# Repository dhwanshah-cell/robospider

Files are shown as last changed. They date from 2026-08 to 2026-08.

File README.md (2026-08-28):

# RoboSpider

A 12-DOF sprawled quadruped, simulated in MuJoCo and sized against the servos
it will actually be built with.

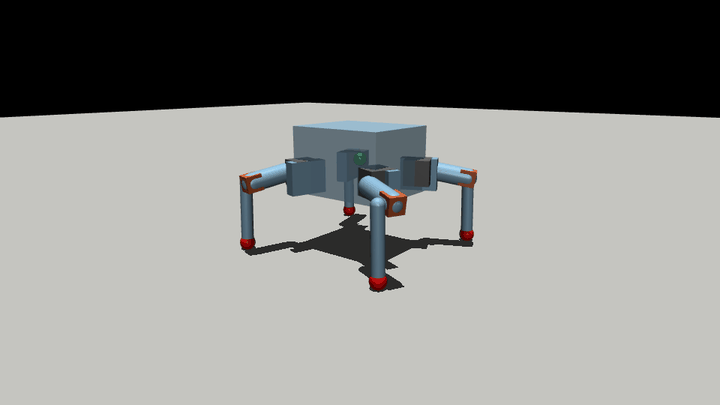
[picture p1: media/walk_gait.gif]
walking


*Crawl gait, 0.9 Hz. Physics, contacts and real servo torque/speed limits — not
a kinematic playback.*

## Quick start

```bash
pip install mujoco
cd sim
python view.py            # mjpython view.py on macOS
python view.py --wiggle   # random policy across all 12 joints
```

`sim/cubebot.xml` is a complete MuJoCo model using **primitive geoms only — no
mesh files required**. `sim/cubebot.urdf` is the same robot for ROS and other
tools, generated from the MJCF with matching masses and inertias.

## The robot

| | |
|---|---|
| DOF | 12 (4 legs × yaw / pitch / knee) + free base |
| mass | 751.7 g |
| stand height | 100 mm on four feet |
| walking | ~4 cm/s at 1.0 Hz crawl |
| timestep | 2 ms, `implicitfast` (MJX-compatible) |
| sensors | trunk framequat / gyro / accelerometer / velocimeter, 4× foot touch |

Femur 48.00 mm, tibia 78.82 mm, leg reach 126.82 mm, foot ball r 8.5 mm.

Leg splay is **FL +23.83°, FR −23.83°, BL +106.23°, BR −106.23°**. The rear pair
is *not* a mirror of the front — a naively mirrored rig will produce subtly
wrong angles everywhere.

## Servos

Rated at 4.8 V throughout, which is the conservative column.

| joint | servo | stall | speed |
|---|---|---|---|
| yaw | TowerPro SG90 | 1.8 kg·cm (0.1765 N·m) | 0.10 s/60° |
| pitch, knee | TowerPro SG92R | 2.5 kg·cm (0.2452 N·m) | 0.10 s/60° |

Modelled as position actuators with `kp = stall / 8°` and
`kv = stall / no_load_speed`, forcerange clamped at stall — so a joint asked for
more than the hardware can give **lags** rather than magically delivering it.

Validated across standing, squatting, ±16° body pitch, ±14° roll, all four
tripod stances, walking at 0.8 and 1.0 Hz, and a 144 mm wall-climb pose:

| joint | worst | RMS | saturated |
|---|---|---|---|
| yaw | 74–84% | 14% | **0** |
| pitch | 80–87% | 31% | **0** |
| knee | 64–74% | 12% | **0** |

Nothing saturates in any case tested.

## Things that turned out to be counter-intuitive

**Walking loads the shoulder; climbing loads the knee.** Sizing for one leaves
you short on the other. The knee peaks at 74% walking but needs 0.205 N·m with a
foot planted on a 144 mm wall — which an MG90S (1.8 kg·cm) cannot deliver at all.

**Slowing down does not relieve the servos.** Shoulder torque in stance is the
robot's weight on a 48 mm lever arm — static, and independent of leg speed. RMS
load is flat between 0.8 and 1.0 Hz (39% vs 38%) and *rises* below 0.5 Hz, while
speed more than halves. Slowing down buys no thermal relief and costs the
distance; stand the robot taller instead.

**A bigger servo is not the answer.** An MG996R has 5× the torque but half the
speed, four times the mass, and its 19.7 mm body does not fit a 15.0 mm hip
bracket or a 15.5 mm femur. Fitting one to the knee roughly doubles shoulder
swing inertia.

**Walls beat infill for the leg.** In bending, stress lives at the outer fibres
and infill sits at the neutral axis. Going 3→5 perimeters buys 21% stiffness;
going 15%→40% infill buys 4%.

See [`docs/LEG_TORQUE_MATH.md`](docs/LEG_TORQUE_MATH.md) for the derivations and
how each was validated.

## Layout

```
sim/     cubebot.xml, cubebot.urdf, view.py
cad/     step-assembly/       complete 28-part STEP assembly
         stl-real/            the actual printable parts
         stl-collision-proxies/   URDF stand-ins — see DO_NOT_PRINT.txt
         urdf-original/       original export — see MASSES_ARE_FAKE.txt
docs/    leg statics, fastener census, handoff, params
tools/   sim, joint-control panel, gait generator, mass model, audits
data/    recorded takes and poses
media/   gait and climb renders
```

The complete assembly is available as a single STEP file at
[`cad/step-assembly/cubebot_assembly.step`](cad/step-assembly/cubebot_assembly.step)
— all 28 parts in place, 21 MB, openable in any CAD package. Use it when you need
the real solid geometry rather than the STL surface exports.

## Known limitations

**Mass is now measured.** Printed parts weighed ~300 g including support;
backing out ~15% support gives ~255 g of parts and a **~735 g robot**. The model
here runs at 751.7 g — at or slightly above reality, so the validated loads are
mildly conservative. Effective print fill is ~0.55, not the 0.85 first assumed.

**Trunk component positions are an assumed layout.** The mass model is real —
30 components parallel-axis'd into a proper inertia tensor, with the CoM 11.5 mm
below the case centre because the 18650 cells sit low — but *where* each item
sits inside the case is a sensible guess, not CAD.

**The URDF has no floating base.** Standard for URDF: the root link welds to the
world, so a loader reports only the leg mass until you add a free-flyer joint.
The MJCF has a proper free joint.

**Three files in `cad/stl-collision-proxies/` are not real parts** — two solid
slabs and a 12-triangle cuboid, stored in metres. Print from `cad/stl-real/`.

**`legstudy/stairs.py` (not shipped here) is unvalidated** and disagrees with
every other result; a hand-scripted climb through it failed at every height for
trajectory reasons, not physical ones.

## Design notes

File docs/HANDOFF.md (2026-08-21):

# CubeBot — HANDOFF

**Read this first**, then `docs/LEG_TORQUE_MATH.md` for the derivations.
Repo: https://github.com/dhwanshah-cell/robospider (public)

---

## WHERE THINGS STAND — 21 Aug 2026

**All parts are printed. Assembly day. Demo is Saturday 22 Aug.**

| | |
|---|---|
| servos | **SG90 / MG90S class (1.8 kg·cm @4.8 V) on all 12** — what is in hand |
| robot mass | **~735 g — MEASURED, no longer an estimate** |
| sim validated at | 751.7 g (at/above real, so slightly conservative) |
| gait for the demo | **1.0 Hz, 55 mm step, +10 mm stance height** -> ~4 cm/s (do not slow it; see #2) |
| blocker | **11 x M3 screws short** (see Fasteners) |

### The mass question is CLOSED
Printed parts weighed **~300 g including support**; backing out ~15% support gives
~255 g of parts and a **~735 g robot**. My earlier model assumed 0.85 effective
fill and predicted 397 g of parts / 873 g robot — **that was wrong**. Real fill is
**~0.55**, because 15% infill on thin-walled parts is far lighter than I credited.

The feared 873 g case (which would have put the pitch servos at their limit)
**does not happen**. Conversion for anything printed later at these settings:
**~0.67 g per cm³ of part volume**.

---

## SERVOS — decided and validated

Demo runs on the **SG90/MG90S** set already owned. Validated across standing,
squatting, ±16° body pitch, ±14° roll, all four tripod stances, walking at 0.8
and 1.0 Hz, and a 144 mm wall-climb pose:

| joint | worst | RMS | saturated |
|---|---|---|---|
| yaw | 74–84% | 14% | **0** |
| pitch | 80–87% | 31% | **0** |
| knee | 64–74% | 12% | **0** |

Nothing saturates. Margin on the shoulders is thin but real.

**Upgrade path, if climbing ever matters:** the knee needs **0.205 N·m** with a
foot loaded on a 144 mm wall, which an MG90S (1.8 kg·cm) **cannot** deliver —
116% of stall. **SG92R (2.5 kg·cm, ~Rs 152 at Robu, 9 g, same 0.10 s/60° speed)**
clears it at 84% and is the only in-stock micro-format part that does. MG92B
(3.1) would be ideal but is unobtainable in India.

**MG996R does not fit.** 19.7 mm smallest dimension against a **15.0 mm hip
bracket and 15.5 mm femur**. Micro format is a hard CAD constraint, not a
preference. Fitting one to the knee also roughly doubles shoulder swing inertia.

**Counterfeit warning:** genuine TowerPro has **4 screws in the base** and
"TowerPro" **moulded into the plastic**. A relabelled SG90 sold as SG92R puts you
straight back to 1.8 kg·cm.

---

## FOUR RESULTS THAT ARE COUNTER-INTUITIVE

Do not re-derive these; they are measured and documented.

1. **Walking loads the shoulder; climbing loads the knee.** Sizing for one leaves
   you short on the other.
2. **Slowing down does not relieve the servos.** Shoulder torque in stance is
   the robot's weight on a 48 mm lever arm — a *static* load, independent of how
   fast the leg moves. Duty factor is fixed at 0.75, so each leg carries it 75%
   of every cycle whatever the frequency. Measured, all-SG90:

       0.80 Hz -> pitch RMS 45%, 1.85 cm/s      0.40 Hz -> 51%, 1.01 cm/s
       0.60 Hz -> 47%, 1.77 cm/s                0.30 Hz -> 54%, 0.53 cm/s
       0.50 Hz -> 49%, 1.18 cm/s                0.25 Hz -> 56%, 0.37 cm/s (saturates)

   At 0.8 vs 1.0 Hz specifically: RMS is the same (39% vs 38%), pitch/knee peaks
   are slightly *higher* at 1.0 Hz, yaw is lower, and 1.0 Hz covers 2.2x the
   ground. So slowing down buys no thermal relief and costs most of the speed;
   below ~0.5 Hz it actively makes the load worse. **If it struggles, stand it
   taller (item 3) rather than slowing it down.**
3. **Stand tall, never crouch.** +10 mm stance is the single biggest load
   reduction; crouching 12 mm pushes pitch to 100% and it starts saturating.
4. **Walls beat infill for the leg.** In bending, stress is at the outer fibres
   and infill sits at the neutral axis: 3->5 perimeters buys 21% stiffness,
   15%->40% infill buys 4%.

---

## FASTENERS — there is a live shortfall

Measured from the real STLs. **No nut traps anywhere** — every screw self-taps
into plastic, so pilot count = screw count: **58 M2, 15 M3**.

| size | bought | needed | **buy** |
|---|---|---|---|
| M2 | 46 (32×8, 10×10, 4×15) | 58 | **+12 × M2×8** |
| M3 | **4** (M3×10) | **15** | **+12 × M3×10, +6 × M3×6** |
| M4 | 0 | 16? | **verify first** |

**M3×6 is not a spare** — three Body Frame pilots are the Ø3.1 stepped holes at
only **3 mm deep**; a 10 mm screw bottoms out.

**M4 unresolved.** 16 × Ø4.0–4.8 holes sit beside Ø7.5 bores on the Leg and
Leg-Body Connector — that is the hip pivot, so they are more likely **pins or
shoulder bolts than screws**. Check whether the Ø4.8 runs clean through.

---

## ASSEMBLY FACTS THAT BITE

**Leg mount angles are NOT mirrored front-to-rear:**

    FL  +23.83°     FR  -23.83°
    BL +106.23°     BR -106.23°

**All six leg parts are mirror-symmetric** (verified against a sampling noise
floor) — the four legs are **identical**, no left/right handing. Handedness comes
from the mount angles only.

**Zero-pose convention:** `ctrl = 0` means **femur HORIZONTAL, tibia VERTICAL**.
Neutral stance = body **103 mm** up, feet at **(±99.5, ±99.1) mm** — a near-square
199 × 198 mm footprint. If the footprint is not square and ~200 mm, a leg is
mounted wrong.

**Joint limits:** yaw ±91.7°, pitch ±80.2°, knee ±126.1°.

**Centre every servo BEFORE assembly** and mark the spline. A horn fitted
off-centre gives a joint whose range is wrong in a way that stays invisible until
the robot walks sideways.

**Power:** stagger servo startup in **groups of 3, 100 ms apart**. Twelve servos
at once draws a surge the 7 A UBEC folds back on. The 2200 µF cap absorbs
switching transients but does **not** extend the current budget (it buys
sub-milliseconds). Keep the Pi rail separate.

---

## TOOLING

    scripts/sim_joints.py    physics sim + IPC        (needs mjpython)
    scripts/joint_panel.py   control window           (python3, tkinter)

Two processes because macOS will not share a main thread between tkinter and the
MuJoCo viewer; they talk through `cmd.json` / `state.json`.

    mjpython scripts/sim_joints.py --wall 0.1442 --from-pose pose_current.json \
             --yaw SG90 --pitch SG92R --knee SG92R --strip-factor 3.5
    python3 scripts/joint_panel.py

Panel has per-joint ±  at a set deg/s, multi-select, LINK groups with per-member
sign, leg locks (shin-angle / foot-height, exact closed forms), a d-pad driving
the crawl gait, and continuous recording with idle frames dropped (~78% of a raw
take is the robot standing still).

**Gear-strip model:** a servo cannot strip its own gears by driving — the motor
tops out at stall. Failure is external back-drive. Proxy is
`|qfrc_actuator + qfrc_constraint|` vs `strip_factor × stall`. **`--strip-factor`
is a dial, not a measurement** (nylon ~2–3×, POM/carbon ~3–4×, metal 5×+) and it
models overload only, **not fatigue**.

---

## THINGS THAT ARE WRONG AND SHOULD NOT BE TRUSTED

**`cad/CubeBot_RL/.../meshes/*.stl` are URDF collision proxies, not parts.**
`Bottom_case.stl` and `Leg_middle_part.stl` are **solid slabs** (99% of bbox);
`Top_case.stl` is a **12-triangle cuboid**. Stored in metres. The real geometry is
in `~/Downloads/TEMP/CAD/bom-export-20260819T105659/stl-files/` and in the repo
under `cad/stl-real/`. `Top_Case_HD.stl` IS real and is the **Body Frame**.

**The original URDF's masses are unit-density artifacts** — every `<mass>` equals
the mesh volume in m³; the whole robot sums to **1.06 g**. Use `sim/cubebot.urdf`
from the repo instead (real masses, no mesh deps). Note URDF has **no floating
base**: a loader reports only leg mass until you add a free-flyer joint.

**`legstudy/stairs.py` is unvalidated**, has never been run by `run.py`, and
disagrees with every independent check. Delete or fix it.

**My hand-scripted climb trajectories failed at every height** for trajectory
reasons, not physical ones. Kinematic playback with no physics let feet pass
through a wall (41/41 frames, 54 mm deep). **Any climb claim must survive a
forward-dynamics replay with contacts** before it means anything.

---

## OPEN ITEMS

1. **Resolve the M4 holes** — pins or screws. Blocks final assembly.
2. **Phase 0 Colab/MJX half** — `notebooks/phase0_colab.ipynb`, written, never run.
   Needs a GPU runtime.
3. **Phase 1 actuator characterisation** — the phase that decides whether any RL
   policy transfers. Bench one servo: step response, max speed under load,
   deadband, stall. Fit a rate-limited position model with 30–80 ms latency.
4. **Push the corrected mass to the repo** — README and this file still said
   "±120 g, nothing weighed" before today's measurement.
5. **Semi-SLAM with preloaded images** — on the project checklist, not started.

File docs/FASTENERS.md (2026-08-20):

# CubeBot fasteners

Hole census measured directly from the real STLs by cross-section sweeping
(slice each part on all three axes, classify internal voids by circularity and
corner count, stack consecutive slices into features). Diameters carry roughly
**±0.2 mm** because the exported meshes are decimated to ~10k triangles — the
Ø1.8 / 1.9 / 2.0 spread is almost certainly one nominal size.

## Holes, by part

    Servo Casing 1  x4   7x Ø1.8
    Servo Casing 2  x4   2x Ø1.8, 4x Ø2.3
    Servo Casing 3  x4   1x Ø2.3
    Leg-Body Conn.  x4   2x Ø4.8, 1x Ø7.5
    Leg             x4   2x Ø1.8, 1x Ø4.0, 1x Ø4.8, 2x Ø7.5
    Top Cover       x1   2x Ø1.8
    Bottom Cover    x1   2x Ø2.0, 4x Ø3.3, 4x Ø3.5, 12x Ø6.0
    Body Frame      x1   4x Ø1.9, 6x Ø2.0, 3x Ø3.1, 8x Ø3.3, 7x Ø3.5, 4x Ø6.0

## Totals

| Ø mm | holes | role | size |
|---|---|---|---|
| 1.8 | 46 | pilot | M2 |
| 1.9 | 4 | pilot | M2 |
| 2.0 | 8 | pilot | M2 |
| 2.3 | 20 | clearance | M2 |
| 3.1 | 3 | pilot (only 3 mm deep) | M3 |
| 3.3 | 12 | pilot | M3 |
| 3.5 | 11 | clearance | M3 |
| 4.0 | 4 | clearance | M4? |
| 4.8 | 12 | clearance | M4? |
| 6.0 / 7.0 / 7.5 | 29 | **not fasteners** — bearings, shafts, cable routes | |

**There are no nut traps anywhere in this design.** Every screw self-taps into a
plastic boss, so the pilot count is the screw count: **58 M2, 15 M3**.

## Versus the purchased BOM

| size | BOM bought | needed | shortfall |
|---|---|---|---|
| M2 | 46 (32×8, 10×10, 4×15) | 58 | **+12** |
| M3 | 4 (M3×10) | 15 | **+11** |
| M4 | 0 | 16? | **unresolved** |

Buy: **+12 M2×8, +12 M3×10, +6 M3×6**. The M3×6 is not a spare — three of the
Body Frame pilots are the Ø3.1 stepped holes at only **3 mm deep**, and a 10 mm
screw bottoms out in them.

## The M4 question — verify before ordering

Sixteen Ø4.0–4.8 holes sit **2 per Leg-Body Connector and 2 per Leg**, directly
beside Ø7.5 bores that are clearly bearing or servo-horn seats. That is the hip
pivot. They are more likely **pins or shoulder bolts than screws**, since a
threaded fastener biting plastic at a rotating joint is poor practice.

Open one Leg-Body Connector and check whether the Ø4.8 runs clean through or
lands in a boss. Through-hole beside a bearing seat -> dowel pin or shoulder
screw, not a machine screw.

## Caveat

Holes were counted in **isolated parts, not an assembly**, so which hole pairs
with which is inferred. Quantities are right to within a few; length assignment
beyond what the original BOM specifies is inference.

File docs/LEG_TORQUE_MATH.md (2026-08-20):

# CubeBot leg statics — the equations, and what they imply

Everything here is derived from the CAD geometry and **checked against the
simulator**, not quoted from a textbook. Where a number is measured, the
measurement is given. Where something is assumed, it says so.

## Geometry (from the CAD, exact)

| | |
|---|---|
| femur (pitch axis → knee axis) | **48.00 mm** |
| tibia (knee axis → foot centre) | **78.82 mm** |
| tibia lateral offset | 17.00 mm |
| yaw → pitch offset | (25.0, 17.0, 7.5) mm |
| hip mounts | (±46.5, ±38.5, −23.2) mm |
| leg splay (mount yaw) | FL +23.83°, FR −23.83°, **BL +106.23°, BR −106.23°** |
| foot ball radius | 8.5 mm |
| total leg reach | 126.82 mm |
| nominal stand height | 103.0 mm |

The rear splay is **±106°, not mirrored ±156°**. A naively mirrored rig will not
match the robot.

## 1. Knee torque

The ground reaction at the foot is essentially vertical. The knee's moment arm
is the **horizontal** distance from the knee axis to the foot, which is the
tibia projected onto the horizontal:

```
    tau_knee  =  F_grf  ×  L_tibia  ×  sin(phi)

    phi = shin angle from vertical
```

* `phi = 0` (shin vertical) → arm 0 → **zero knee torque**. The force runs
  straight down the tibia through the knee axis.
* `phi = 90°` (shin horizontal) → arm = full 78.82 mm → **maximum**.

**Validated** against a recorded take: correlation between `sin(phi)` and the
measured horizontal knee→foot arm = **0.998**. Over that take the arm ranged
**6.9 → 80.6 mm**, a 12× swing — which is why the same servo read 70% of stall
at one moment and over 100% at another. The servo did not change; the geometry did.

## 2. Shoulder-pitch torque

Same logic, one link further out:

```
    tau_pitch  =  F_grf  ×  d_horizontal(pitch axis → foot)
```

The femur is the lever. This is why the 48 mm femur length sets the whole
shoulder-torque budget, and why shortening it is the only geometric lever on
stance load. Measured: in stance the ground reaction is **14×** the leg's own
self-weight, so self-weight is only ~7.7% of the shoulder load — lighter servos
cannot fix a stance-torque problem.

## 3. The two joints pull in opposite directions

```
    knee  wants the shin VERTICAL           arm = L_tibia · sin(phi)      -> 0
    pitch wants the foot UNDER THE HIP      arm = hip-to-foot horizontal  -> 0
```

They cannot both be satisfied: the knee lies **between** the hip and the foot,
so tucking the foot under the hip tilts the shin, and standing the shin upright
pushes the foot outboard.

Swept at 100 mm body height, one leg carrying a tripod share (2.26 N, 690 g
robot), SG92R (2.5 kg·cm) at both joints:

| foot x | shin | pitch arm | knee arm | pitch | knee | worst |
|---|---|---|---|---|---|---|
| 20 mm | 168° | 12.8 mm | 18.9 mm | 12% | 17% | **17%** |
| 36 | 164° | 5.0 | 24.3 | 5% | 22% | 22% |
| 52 | 163° | **2.9** | 27.4 | **3%** | 25% | 25% |
| 68 | 167° | 12.5 | 25.0 | 12% | 23% | 23% |
| 84 | 173° | 24.2 | **17.4** | 22% | **16%** | 22% |

Minimising **either** joint alone makes the other worse (see the 52 mm row).

### The rule

> **Balance the two moment arms; do not minimise either.**
> Optimum in this sweep: foot ~20 mm ahead of the body origin, body ~85 mm,
> arms 12.8 vs 18.5 mm, worst joint **17%**.

Good candidate for a Phase 2 reward term: penalise `max(pitch_arm, knee_arm)`
and let the policy discover the tradeoff.

**Caveats.** Static arms only — swing adds inertial load this ignores. And it
ignores stability: a 20 mm footprint is a tiny support polygon, and the walking
sweep found foot spreads below ~70% of nominal unwalkable (the robot topples
before the load benefit arrives).

## 4. Forward kinematics (planar, exact)

Vertical drop from the pitch axis to the foot centre:

```
    drop  =  L_femur · sin(q_pitch)  +  L_tibia · cos(q_pitch + q_knee)
```

Verified against MuJoCo FK to 0.01 mm. Two useful consequences, both exactly
solvable (one constraint, one free joint), both implemented in `joint_panel.py`:

**Shin-angle lock** — hold the shin's angle to the ground while driving the femur:

```
    delta_q_knee  =  - delta_q_pitch
```

Exact: shin angle held at 0.00° across the full range.

**Foot-height lock** — hold the foot at a constant height while driving the femur:

```
    q_knee  =  arccos( (drop_target - L_femur · sin(q_pitch)) / L_tibia )  -  q_pitch
```

Verified: foot drop held at 78.82 mm for q_pitch 0→40°, knee values matching a
MuJoCo bisection to 0.01°.

**You cannot lock the foot's full 3D position while driving a joint.** The leg
has 3 DOF; pinning a 3D point consumes all three and leaves nothing to drive.

## 5. Convention gotcha that cost real time

`leg_ik` targets the foot **site**, which sits at the **centre of the foot ball**.
Placing a foot target at the surface height (`z = 0` for the floor, `z = H` for a
tread) buries the ball one radius — **8.5 mm** — into the ground.

```
    correct:   z_target = surface_height + foot_radius
```

The leg study's own standing height already assumes this:
`z0 = -(hip_z + foot_z - foot_radius) = 103.0 mm`.

Getting this wrong made the servos press into the floor for the whole stance
phase and inflated every walking load — yaw by 78%, knee by 12%.

## 6. Servo reference (4.8 V column, always)

| servo | stall | s/60° | mass | smallest dim | fits leg parts? |
|---|---|---|---|---|---|
| SG90 | 1.8 kg·cm (0.1765 N·m) | 0.10 | 9.0 g | 11.8 mm | yes |
| MG90S | 1.8 (0.1765) | 0.10 | 13.4 g | 12.2 mm | yes |
| SG92R | 2.5 (0.2452) | 0.10 | 9.0 g | 12.2 mm | yes |
| MG92B | 3.1 (0.3040) | 0.10 | 13.8 g | 12.2 mm | yes (unobtainable in IN) |
| MG996R | 9.4 (0.9218) | 0.17 | 55.0 g | **19.7 mm** | **NO** |

**The hip bracket is 15.0 mm thick and the femur 15.5 mm.** The MG996R's 19.7 mm
smallest dimension does not fit either, in any orientation. Micro format is a
hard constraint of the current CAD, not a preference.

Emulated position servo (matches `params.yaml`):

```
    kp = stall / proportional_band      band = 8° = 0.1396 rad
    kv = stall / no_load_speed
    tau = clamp( kp·(cmd - q) - kv·qdot , ±stall )
```

Speed demand of the swing profile, per Hz of gait:
`yaw 1.94, pitch 4.71, knee 5.56 rad/s`. Usable ceiling ≈ 70% of no-load.

## 7. Gear stripping

A servo **cannot strip its own gears by driving** — the motor tops out at stall
and the train is built for that. Gears fail when something **external
back-drives** the output (a fall, a landing, a jammed leg) and the train must
react a torque far above stall. Stress proxy used in `sim_joints.py`:

```
    tau_gear  =  | qfrc_actuator + qfrc_constraint |     (per joint DOF)
    stripped  when  tau_gear > strip_factor × stall
```

`--strip-factor` is a **dial, not a measurement** — no trustworthy published
strip torque was found for these servos. Rough bands: nylon 2–3×, POM/carbon
3–4×, metal 5×+. Models overload failure only; **does not model fatigue**, which
is the other way POM gears die when run at 80% of stall for hours.

## 8. Measured loads, for reference

| case | binding joint | note |
|---|---|---|
| walking, all-SG90, 690 g | pitch 84% pk / 43% RMS | knee comfortable |
| walking, all-MG92B, 748 g | pitch 63% pk / 28% RMS | best build tested |
| wall climb, foot on 144 mm tread | **knee 0.205 N·m** | MG90S 116% (fails), SG92R 84%, MG92B 67% |
| yaw, every case tested | ≤68% pk, 5–27% RMS | SG90 is correctly sized |

**Walking loads the shoulder; climbing loads the knee.** Sizing for one leaves
you short on the other.

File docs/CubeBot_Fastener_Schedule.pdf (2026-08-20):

# CubeBot — Fastener Schedule

Hole-by-hole fastener sizes measured from the CubeBot 3D model ( ~/cubebot-legstudy/cad/CubeBot_RL/cubebot/urdf/meshes/ )

COMPILED 17 AUGUST 2026 · 7 PARTS EXAMINED · SIZES DERIVED FROM GEOMETRY, NOT FROM A PARTS LIST

The repository contains no BOM. No parts list, no hardware document, and no mention of any fastener designation anywhere in the source. Every size below was measured out of the mesh geometry itself.
There are no nuts in this design. A sweep for hexagonal and square pockets across all seven parts returned zero nut traps. Every fastener threads directly into a plastic boss — specify thread-forming / self-tapping screws, not bolt-and-nut pairs.

### 1 Top_Case_HD — 125 × 40 × 105 mm · 57,124 triangles · the only fully detailed part

Coordinates are the hole centres in the part's own frame, in millimetres.
HOLE | DEPTH | QTY | FASTENER | LOCATION / NOTE
Ø 1.90 – 2.00 | 10 mm blind | 8 | M2 | Case screw bosses (±55, ±38.25) and
(±26.5, ±38.25)
Ø 2.00 | 4 mm | 2 | M2 | Side wall (2.6, ±10.5)
Ø 3.10
c'bore Ø 3.50

3 mm
c'bore 2 mm
3 | M3 | Stepped hole — Ø3.5 lead-in through the wall, Ø3.1
thread-forming pilot behind it.
z = −35.21 / −39.21 / −43.21
Ø 3.30 | 9.2 mm | 4 | M3 | Enters from the bottom face (±42, ±27)
Ø 3.50 | 5 mm | 4 | M3 clearance | (32.45 / −25, ±24.5)
Ø 6.00 | 3.5 mm | 4 | not a fastener | Bearing seat or cable grommet
Ø 20.00 | 5 mm | 1 | not a fastener | Connector port (−60.22, 15, 0)

### 2 Remaining parts

Simplified URDF collision meshes, stored in metres and rescaled ×1000 to measure. Holes are cleanly tessellated, so diameters are exact; no counterbores or secondary features are modelled.

PART | HOLE | QTY | FASTENER | NOTE
Bottom_case | Ø 4.25 through 18.2 mm | 4 | M4 clearance | (±46.5, ±38.5) — or Ø4
standoffs
Leg_middle_part | Ø 3.00 through 34 mm | 2 | M3 | Pivot bolt or 3 mm shaft, (±24)
Part_1 | Ø 5.00 (2 × 6 mm, 1 × 15 mm) | 3 | not a bolt | Reads as shaft / bearing
Part_1_1 | Ø 6.54 × 6 mm | 2 | not a bolt | Bearing seat
Foot | none | — | — | No holes of any size
Top_case | none | — | — | 12-triangle bounding-box
placeholder

### 3 Shopping list

Lengths follow the measured engagement depths. All screws thread into plastic — no nuts required.
M2 × 8–10 mm | ×8 | Self-tapping, into the 10 mm case bosses
M2 × 4–5 mm | ×2 | Self-tapping, side wall
M3 × 5–6 mm | ×3 | Thread-forming, into the Ø3.1 stepped pilots
M3 × 10 mm | ×4 | Into the Ø3.3 bottom-face bosses
M3 × 6 mm | ×4 | Through the Ø3.5 clearance holes
M3 × 35–40 mm | ×2 | Leg pivots, through the 34 mm Ø3.0 bores
M4 × 25 mm + | ×4 | Through the 18.2 mm bottom case, plus engagement

HOW THESE WERE MEASURED
Cross-section sweep along all three principal axes at a 0.25 mm pitch. Loops in each slice were nested by containment; a loop at odd nesting depth is an internal void. Round voids were sized by least-squares circle fit through the loop vertices — CAD places tessellation vertices on the true circle, so this recovers the design diameter regardless of mesh coarseness. Consecutive slices were stacked into single features to recover depth.
Cross-checked with an independent, axis-agnostic pass: faces grouped into smooth-connected patches, each fitted to a cylinder, then classified as a bore or a boss by whether the surface normals face the axis. Both methods agree on every full-circle bore.
Hex and square nut traps were searched for by corner-counting each void loop (6 corners on a circumscribing circle → hex, acrossflats from the enclosed area). None found.
The OBJ set in ~/cubebot-legstudy/assets/ is byte-for-byte the same geometry as the STL set; measuring either gives the same result.

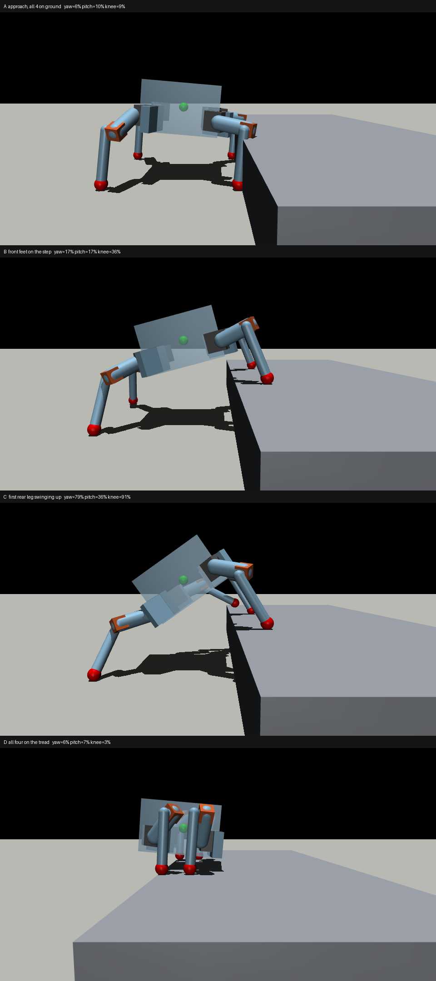
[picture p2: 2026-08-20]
media/climb_75mm.png

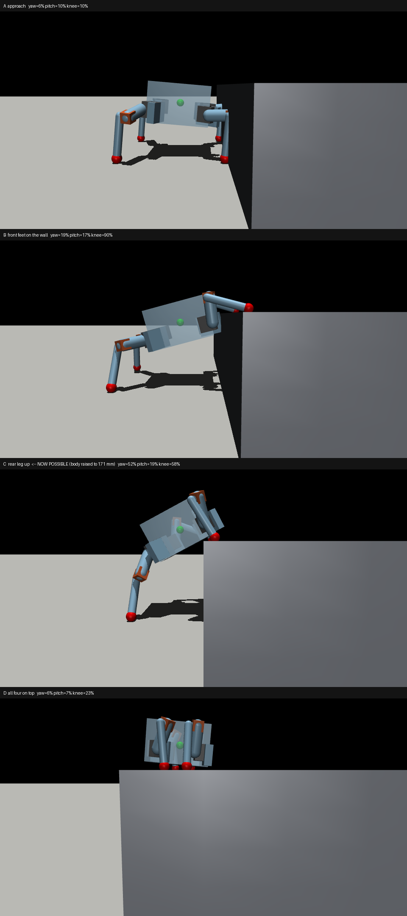
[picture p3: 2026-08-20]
media/wall_144mm_raised.png

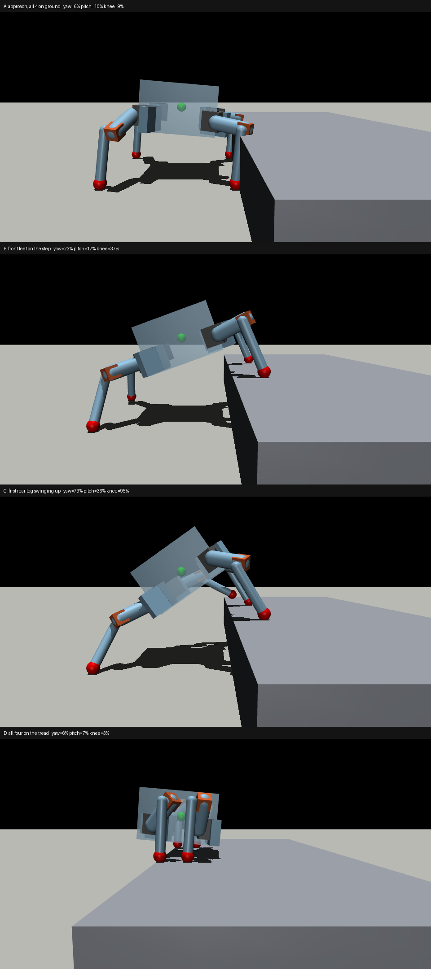
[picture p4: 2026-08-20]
media/climb_80mm.png

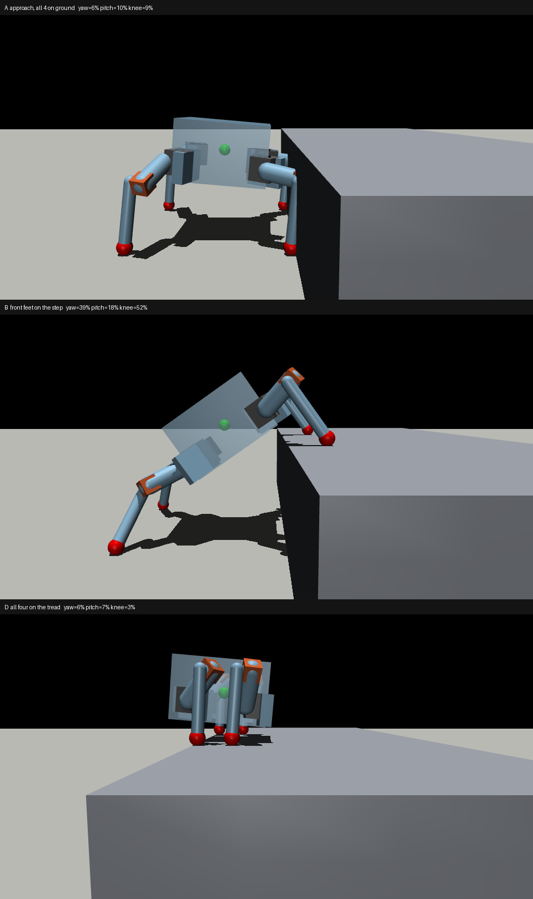
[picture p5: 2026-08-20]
media/climb_130mm.png

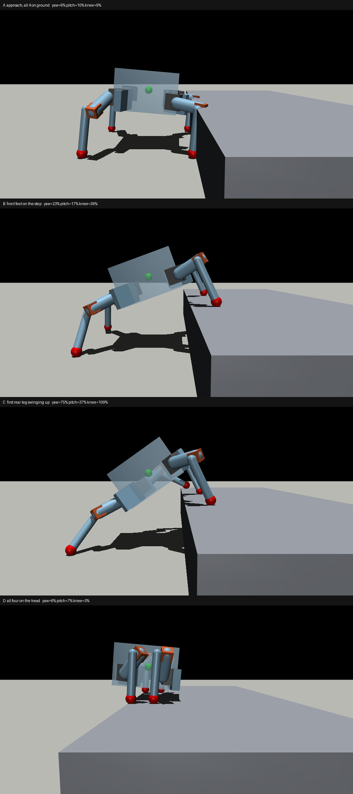
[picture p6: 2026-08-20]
media/climb_90mm.png

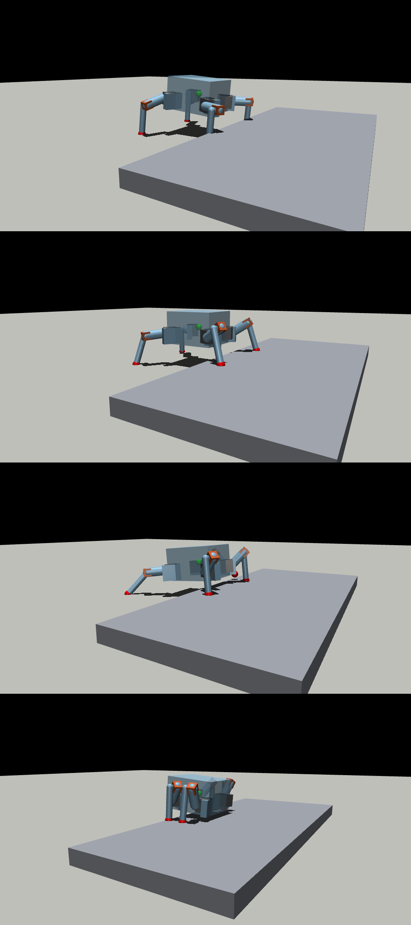
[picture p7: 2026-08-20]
media/climb_30mm.png

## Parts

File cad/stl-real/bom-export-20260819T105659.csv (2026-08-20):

Part Name | STL Download Link | Notes
Body Frame | Download Here
Top Cover | Download Here
Bottom Cover | Download Here
Foot | Download Here
Leg | Download Here
Leg-Body Connector | Download Here
Camera Cover | Download Here
Servo Casing 1 | Download Here
Servo Casing 2 | Download Here
Servo Casing 3 | Download Here

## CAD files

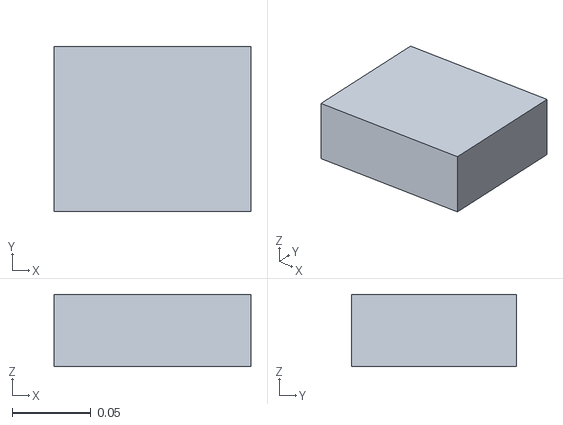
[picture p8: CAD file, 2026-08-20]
cad/stl-collision-proxies/Top_case.stl
0.125 x 0.105 x 0.046

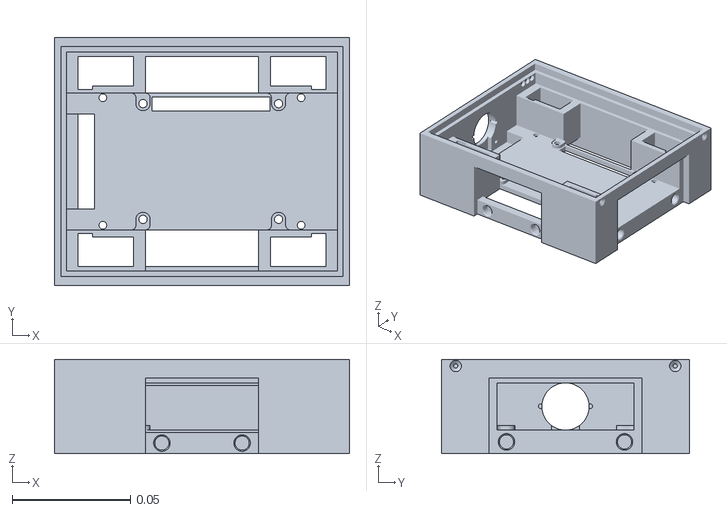
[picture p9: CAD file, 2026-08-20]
cad/stl-real/42zlmowk6v3y-Body_Frame.stl
0.125 x 0.105 x 0.04

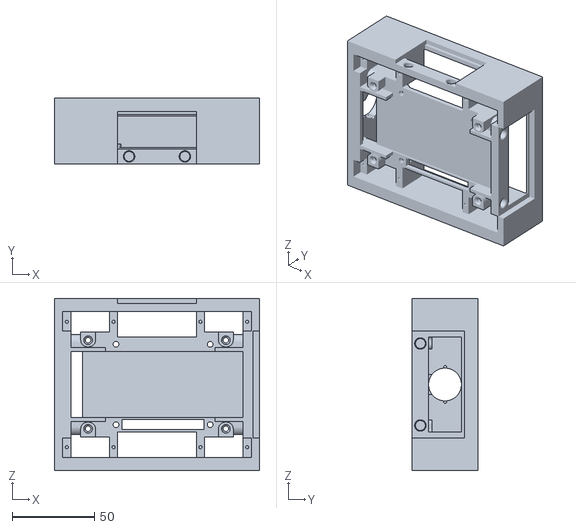
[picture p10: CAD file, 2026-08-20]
cad/stl-collision-proxies/Top_Case_HD.stl
125.0 x 40.0 x 105.0

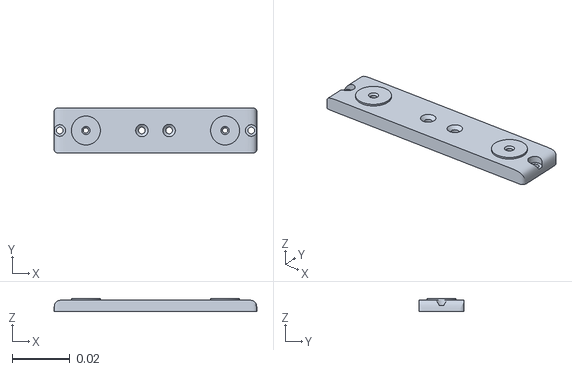
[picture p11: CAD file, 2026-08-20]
cad/stl-real/servo casing2.stl
0.07 x 0.0155 x 0.0045

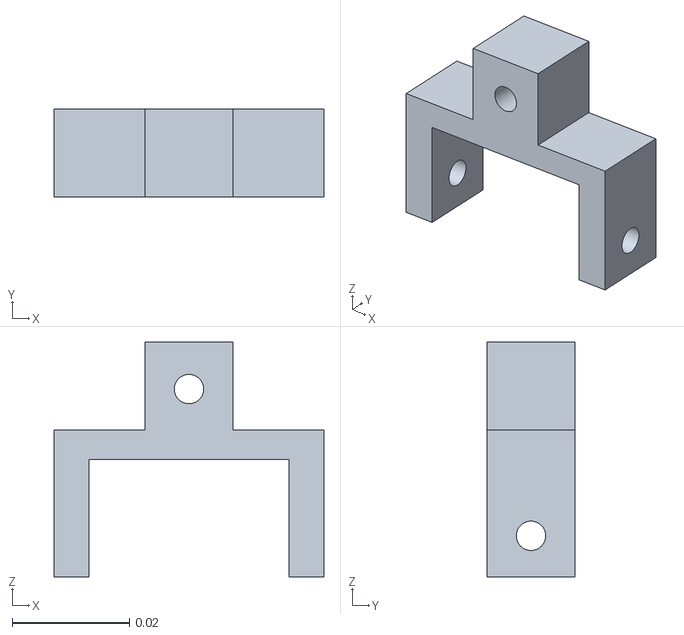
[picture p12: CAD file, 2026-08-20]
cad/stl-collision-proxies/Part_1.stl
0.046 x 0.015 x 0.04

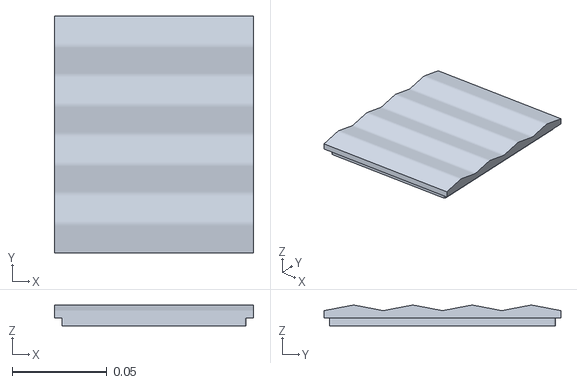
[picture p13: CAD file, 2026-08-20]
cad/stl-real/s4yj81t6fxf0-Top_Cover.stl
0.105 x 0.125 x 0.0109

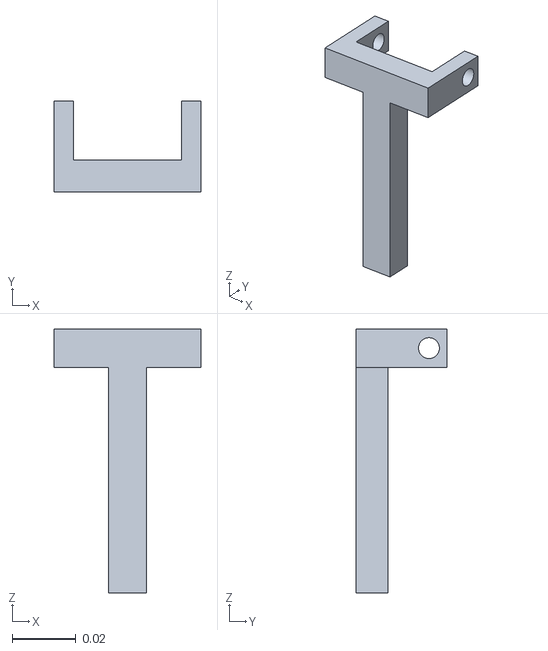
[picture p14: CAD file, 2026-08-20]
cad/stl-collision-proxies/Part_1_1.stl
0.046 x 0.0285 x 0.0828

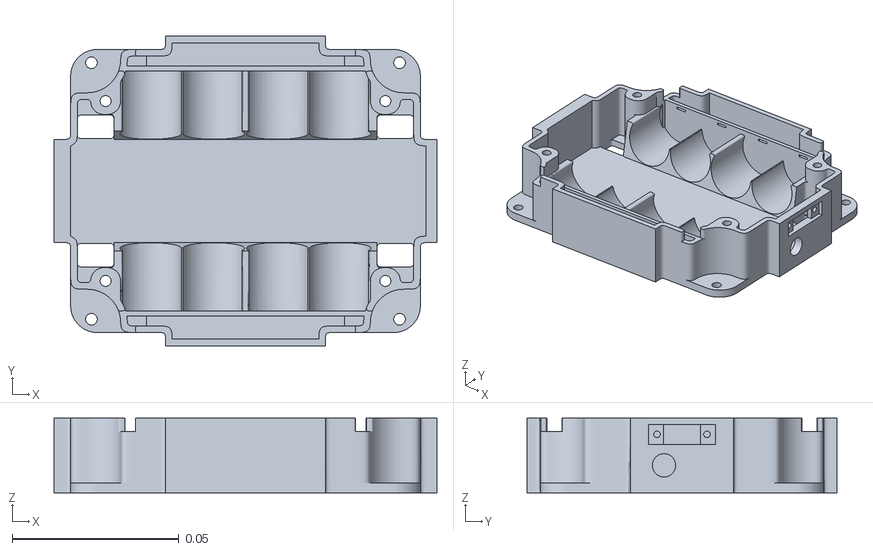
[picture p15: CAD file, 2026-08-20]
cad/stl-real/3ozjznhu8j9f-Bottom_Cover.stl
0.115 x 0.093 x 0.0225

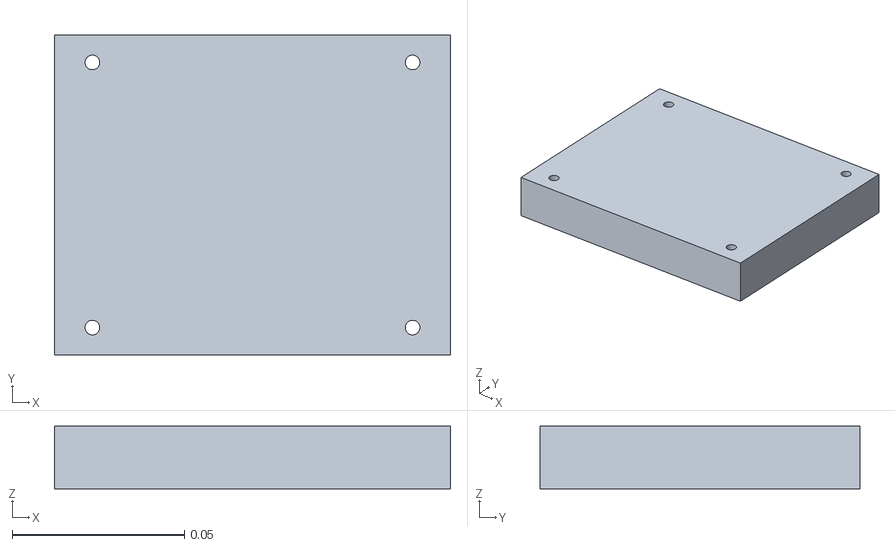
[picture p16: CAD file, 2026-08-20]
cad/stl-collision-proxies/Bottom_case.stl
0.115 x 0.093 x 0.0182

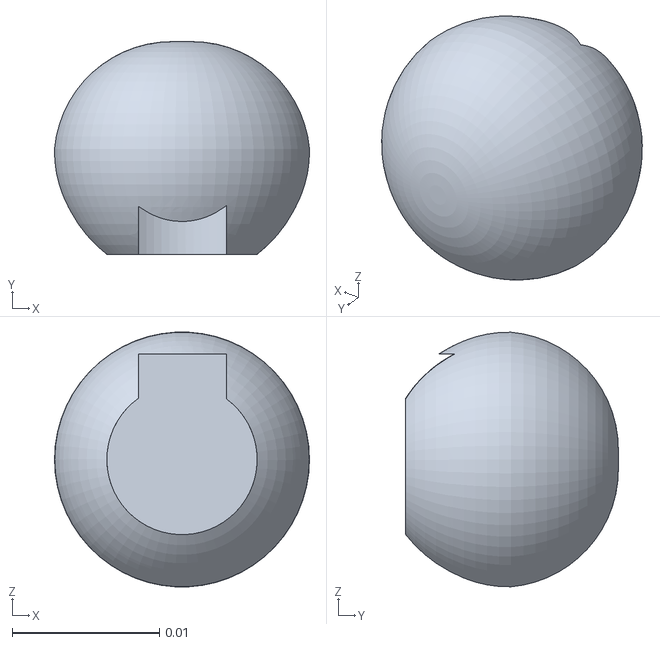
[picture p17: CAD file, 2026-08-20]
cad/stl-real/Foot.stl
0.0173 x 0.0144 x 0.0173

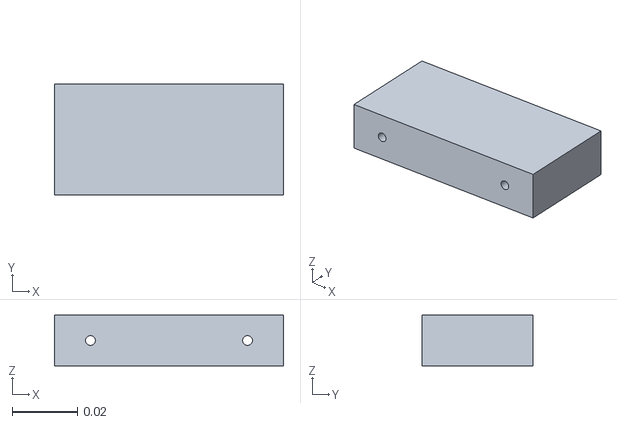
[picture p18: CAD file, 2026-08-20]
cad/stl-collision-proxies/Leg_middle_part.stl
0.07 x 0.034 x 0.0155

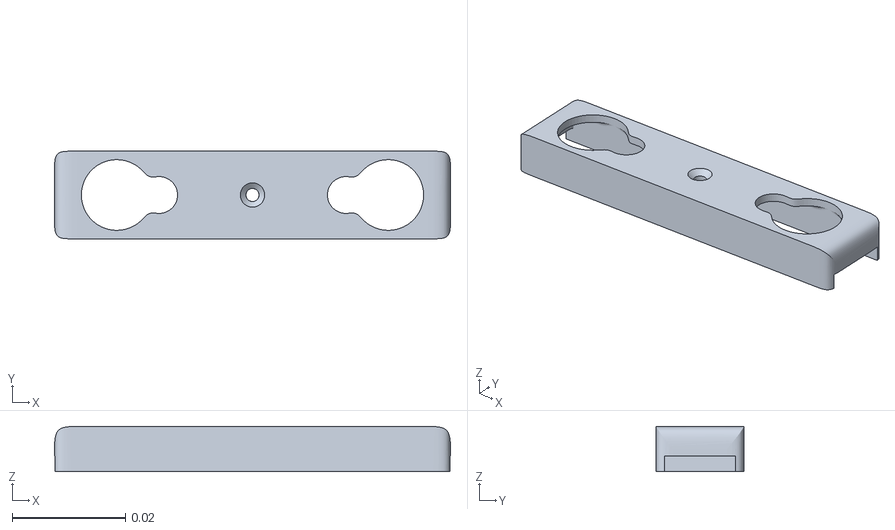
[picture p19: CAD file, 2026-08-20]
cad/stl-real/servo casing3.stl
0.07 x 0.0155 x 0.008

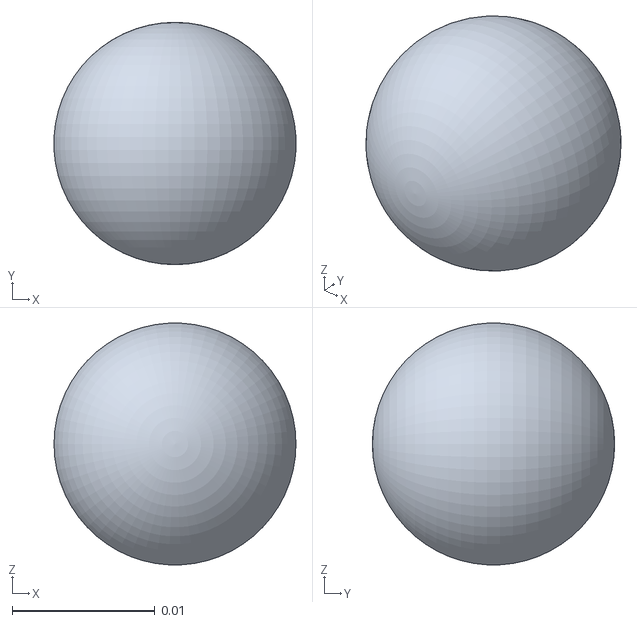
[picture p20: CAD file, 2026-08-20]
cad/stl-collision-proxies/Foot.stl
0.017 x 0.017 x 0.017

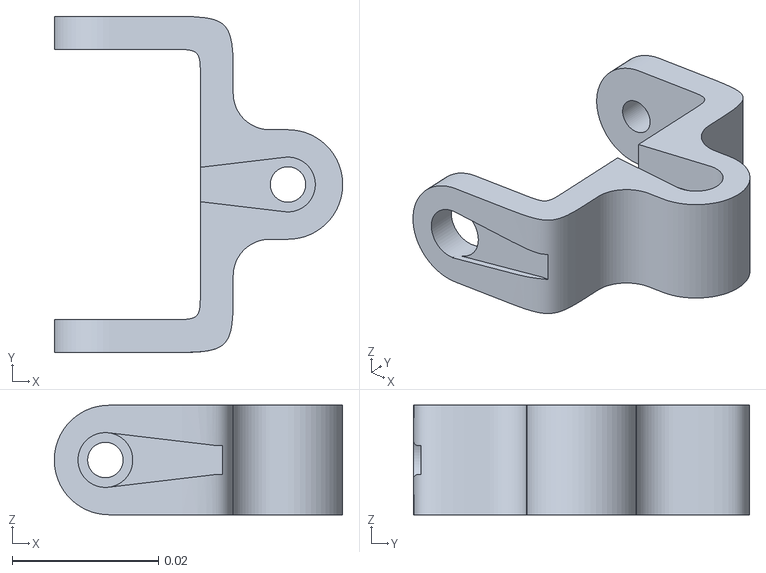
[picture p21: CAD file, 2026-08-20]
cad/stl-real/Leg-Body_Connector.stl
0.0395 x 0.046 x 0.015

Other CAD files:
cad/stl-real/Leg.stl
cad/stl-real/servo casing1.stl
cad/stl-real/y3t8uh5qiyna-Camera_Cover.stl

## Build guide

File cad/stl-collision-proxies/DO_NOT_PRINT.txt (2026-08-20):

These are the URDF *collision proxies* from VGlukhov-git/CubeBot_RL.
THREE OF THEM ARE NOT REAL PARTS:

  Bottom_case.stl       99% of its bounding box  -> a solid slab
  Leg_middle_part.stl   99%                      -> a solid slab
  Top_case.stl          12 triangles             -> a bare cuboid

They are stored in METRES (scale x1000 on import) and exist only so the
physics engine has something to compute contacts against.

Top_Case_HD.stl IS real, and is the same part as "Body Frame" in
../stl-real/ (volumes match to 0.024%) at higher resolution: 57,124
triangles vs 10,320.

Print from ../stl-real/ instead.

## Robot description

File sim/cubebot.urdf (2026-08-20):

<?xml version="1.0"?>
<robot name="cubebot">
  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
  <link name="trunk">
    <inertial>
      <origin xyz="-0.00447377 0.000204821 -0.00986828" rpy="-1.85233 -1.53107 -1.27366" />
      <mass value="0.6347" />
      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
    </inertial>
    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
  </link>
  <link name="FL_hip">
    <inertial>
      <origin xyz="0.0120863 0.0014668 0.0072666" rpy="1.72203 -0.353429 1.59707" />
      <mass value="0.010877" />
      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
    </inertial>
    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
  </link>
  <link name="FL_femur">
    <inertial>
      <origin xyz="0.0409163 0 0" rpy="1.5708 0 1.5708" />
      <mass value="0.0127687" />
      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
    </inertial>
    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
  </link>
  <link name="FL_tibia">
    <inertial>
      <origin xyz="0 0.017 -0.0521092" rpy="0 0 0" />
      <mass value="0.00559622" />
      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
    </inertial>
    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
  </link>
  <link name="FR_hip">
    <inertial>
      <origin xyz="0.0120863 0.0014668 0.0072666" rpy="1.72203 -0.353429 1.59707" />
      <mass value="0.010877" />
      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
    </inertial>
    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
  </link>
  <link name="FR_femur">
    <inertial>
      <origin xyz="0.0409163 0 0" rpy="1.5708 0 1.5708" />
      <mass value="0.0127687" />
      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
    </inertial>
    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
  </link>
  <link name="FR_tibia">
    <inertial>
      <origin xyz="0 -0.017 -0.0521092" rpy="0 0 0" />
      <mass value="0.00559622" />
      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
    </inertial>
    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
  </link>
  <link name="BL_hip">
    <inertial>
      <origin xyz="0.0120863 0.0014668 0.0072666" rpy="1.72203 -0.353429 1.59707" />
      <mass value="0.010877" />
      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
    </inertial>
    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
  </link>
  <link name="BL_femur">
    <inertial>
      <origin xyz="0.0409163 0 0" rpy="1.5708 0 1.5708" />
      <mass value="0.0127687" />
      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
    </inertial>
    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
  </link>
  <link name="BL_tibia">
    <inertial>
      <origin xyz="0 0.017 -0.0521092" rpy="0 0 0" />
      <mass value="0.00559622" />
      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
    </inertial>
    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
  </link>
  <link name="BR_hip">
    <inertial>
      <origin xyz="0.0120863 0.0014668 0.0072666" rpy="1.72203 -0.353429 1.59707" />
      <mass value="0.010877" />
      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
    </inertial>
    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
  </link>
  <link name="BR_femur">
    <inertial>
      <origin xyz="0.0409163 0 0" rpy="1.5708 0 1.5708" />
      <mass value="0.0127687" />
      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
    </inertial>
    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
  </link>
  <link name="BR_tibia">
    <inertial>
      <origin xyz="0 -0.017 -0.0521092" rpy="0 0 0" />
      <mass value="0.00559622" />
      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
    </inertial>
    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
  </link>
  <joint name="FL_yaw" type="revolute">
    <parent link="trunk" />
    <child link="FL_hip" />
    <origin xyz="0.0465 0.0385 -0.0232" rpy="0 0 0.415844" />
    <axis xyz="0 0 1" />
    <limit lower="-1.6" upper="1.6" effort="0.17652" velocity="10.47" />
    <dynamics damping="0.004" friction="0" />
  </joint>
  <joint name="FL_pitch" type="revolute">
    <parent link="FL_hip" />
    <child link="FL_femur" />
    <origin xyz="0.025 0.017 0.0075" rpy="0 0 0" />
    <axis xyz="0 1 0" />
    <limit lower="-1.4" upper="1.4" effort="0.245166" velocity="10.47" />
    <dynamics damping="0.004" friction="0" />
  </joint>
  <joint name="FL_knee" type="revolute">
    <parent link="FL_femur" />
    <child link="FL_tibia" />
    <origin xyz="0.048 0 0" rpy="0 0 0" />
    <axis xyz="0 1 0" />
    <limit lower="-2.2" upper="2.2" effort="0.245166" velocity="10.47" />
    <dynamics damping="0.004" friction="0" />
  </joint>
  <joint name="FR_yaw" type="revolute">
    <parent link="trunk" />
    <child link="FR_hip" />
    <origin xyz="0.0465 -0.0385 -0.0232" rpy="0 0 -0.415844" />
    <axis xyz="0 0 1" />
    <limit lower="-1.6" upper="1.6" effort="0.17652" velocity="10.47" />
    <dynamics damping="0.004" friction="0" />
  </joint>
  <joint name="FR_pitch" type="revolute">
    <parent link="FR_hip" />
    <child link="FR_femur" />
    <origin xyz="0.025 -0.017 0.0075" rpy="0 0 0" />
    <axis xyz="0 1 0" />
    <limit lower="-1.4" upper="1.4" effort="0.245166" velocity="10.47" />
    <dynamics damping="0.004" friction="0" />
  </joint>
  <joint name="FR_knee" type="revolute">
    <parent link="FR_femur" />
    <child link="FR_tibia" />
    <origin xyz="0.048 0 0" rpy="0 0 0" />
    <axis xyz="0 1 0" />
    <limit lower="-2.2" upper="2.2" effort="0.245166" velocity="10.47" />
    <dynamics damping="0.004" friction="0" />
  </joint>
  <joint name="BL_yaw" type="revolute">
    <parent link="trunk" />
    <child link="BL_hip" />
    <origin xyz="-0.0465 0.0385 -0.0232" rpy="0 0 1.854" />
    <axis xyz="0 0 1" />
    <limit lower="-1.6" upper="1.6" effort="0.17652" velocity="10.47" />
    <dynamics damping="0.004" friction="0" />
  </joint>
  <joint name="BL_pitch" type="revolute">
    <parent link="BL_hip" />
    <child link="BL_femur" />
    <origin xyz="0.025 0.017 0.0075" rpy="0 0 0" />
    <axis xyz="0 1 0" />
    <limit lower="-1.4" upper="1.4" effort="0.245166" velocity="10.47" />
    <dynamics damping="0.004" friction="0" />
  </joint>
  <joint name="BL_knee" type="revolute">
    <parent link="BL_femur" />
    <child link="BL_tibia" />
    <origin xyz="0.048 0 0" rpy="0 0 0" />
    <axis xyz="0 1 0" />
    <limit lower="-2.2" upper="2.2" effort="0.245166" velocity="10.47" />
    <dynamics damping="0.004" friction="0" />
  </joint>
  <joint name="BR_yaw" type="revolute">
    <parent link="trunk" />
    <child link="BR_hip" />
    <origin xyz="-0.0465 -0.0385 -0.0232" rpy="0 0 -1.854" />
    <axis xyz="0 0 1" />
    <limit lower="-1.6" upper="1.6" effort="0.17652" velocity="10.47" />
    <dynamics damping="0.004" friction="0" />
  </joint>
  <joint name="BR_pitch" type="revolute">
    <parent link="BR_hip" />
    <child link="BR_femur" />
    <origin xyz="0.025 -0.017 0.0075" rpy="0 0 0" />
    <axis xyz="0 1 0" />
    <limit lower="-1.4" upper="1.4" effort="0.245166" velocity="10.47" />
    <dynamics damping="0.004" friction="0" />
  </joint>
  <joint name="BR_knee" type="revolute">
    <parent link="BR_femur" />
    <child link="BR_tibia" />
    <origin xyz="0.048 0 0" rpy="0 0 0" />
    <axis xyz="0 1 0" />
    <limit lower="-2.2" upper="2.2" effort="0.245166" velocity="10.47" />
    <dynamics damping="0.004" friction="0" />
  </joint>
</robot>

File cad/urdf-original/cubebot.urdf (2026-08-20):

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
<robot name="cubebot">
    <link name="bottom_case">
        <inertial>
            <mass value="0.000193616" />
            <origin xyz="1.64049e-17 -6.01365e-18 -0.0091" rpy="0 -0 0" />
            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
        </inertial>
        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
    </link>
    <link name="foot">
        <inertial>
            <mass value="2.57244e-06" />
            <origin xyz="1.95178e-19 0 0" rpy="0 -0 0" />
            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
        </inertial>
        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
    </link>
    <link name="foot_1">
        <inertial>
            <mass value="2.57244e-06" />
            <origin xyz="1.95178e-19 0 0" rpy="0 -0 0" />
            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
        </inertial>
        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
    </link>
    <link name="foot_2">
        <inertial>
            <mass value="2.57244e-06" />
            <origin xyz="1.95178e-19 0 0" rpy="0 -0 0" />
            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
        </inertial>
        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
    </link>
    <link name="foot_3">
        <inertial>
            <mass value="2.57244e-06" />
            <origin xyz="1.95178e-19 0 0" rpy="0 -0 0" />
            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
        </inertial>
        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
    </link>
    <link name="leg_middle_part">
        <inertial>
            <mass value="3.64093e-05" />
            <origin xyz="-0.024 0.017 -8.67362e-18" rpy="0 -0 0" />
            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
        </inertial>
        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
    </link>
    <link name="leg_middle_part_1">
        <inertial>
            <mass value="3.64093e-05" />
            <origin xyz="0.024 0.017 -2.60209e-18" rpy="0 -0 0" />
            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
        </inertial>
        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
    </link>
    <link name="leg_middle_part_2">
        <inertial>
            <mass value="3.64093e-05" />
            <origin xyz="0.024 0.017 -2.60209e-18" rpy="0 -0 0" />
            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
        </inertial>
        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
    </link>
    <link name="leg_middle_part_3">
        <inertial>
            <mass value="3.64093e-05" />
            <origin xyz="-0.024 -0.017 -8.67362e-18" rpy="0 -0 0" />
            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
        </inertial>
        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
    </link>
    <link name="part_1">
        <inertial>
            <mass value="9.89486e-06" />
            <origin xyz="-0.0105506 0.0075 -3.36383e-19" rpy="0 1.5708 -0" />
            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
        </inertial>
        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
    </link>
    <link name="part_1_1">
        <inertial>
            <mass value="1.62727e-05" />
            <origin xyz="-0.017 0.0216008 -0.0159671" rpy="1.5708 -0 0" />
            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
        </inertial>
        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
    </link>
    <link name="part_1_2">
        <inertial>
            <mass value="9.89486e-06" />
            <origin xyz="0.0105506 0.0075 -4.34904e-18" rpy="0 -1.5708 0" />
            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
        </inertial>
        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
    </link>
    <link name="part_1_3">
        <inertial>
            <mass value="1.62727e-05" />
            <origin xyz="-0.017 -0.0216008 0.0159671" rpy="-1.5708 0 0" />
            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
        </inertial>
        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
    </link>
    <link name="part_1_4">
        <inertial>
            <mass value="1.62727e-05" />
            <origin xyz="0.017 -0.0216008 0.0159671" rpy="-1.5708 0 0" />
            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
        </inertial>
        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
    </link>
    <link name="part_1_5">
        <inertial>
            <mass value="1.62727e-05" />
            <origin xyz="0.017 -0.0216008 0.0159671" rpy="-1.5708 0 0" />
            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
        </inertial>
        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
    </link>
    <link name="part_1_6">
        <inertial>
            <mass value="9.89486e-06" />
            <origin xyz="0.0105506 0.0075 3.36383e-19" rpy="0 -1.5708 0" />
            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
        </inertial>
        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
    </link>
    <link name="part_1_7">
        <inertial>
            <mass value="9.89486e-06" />
            <origin xyz="-0.0105506 0.0075 -3.36383e-19" rpy="0 1.5708 -0" />
            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
        </inertial>
        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
    </link>
    <link name="root" />
    <link name="top_case">
        <inertial>
            <mass value="0.00060375" />
            <origin xyz="1.40295e-18 0 0.023" rpy="0 -0 0" />
            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
        </inertial>
        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
    </link>
    <joint name="fastened_5" type="fixed">
        <origin xyz="0.017 -0.076775 0.017856" rpy="0 -1.5708 -1.5708" />
        <axis xyz="0 0 1" />
        <parent link="part_1_4" />
        <child link="foot_1" />
    </joint>
    <joint name="fastened_6" type="fixed">
        <origin xyz="0.017 -0.076775 0.017856" rpy="1.5708 -3.67911e-16 3.14159" />
        <axis xyz="0 0 1" />
        <parent link="part_1_5" />
        <child link="foot_2" />
    </joint>
    <joint name="fastened_7" type="fixed">
        <origin xyz="-0.017 -0.076775 0.017856" rpy="0 1.5708 1.5708" />
        <axis xyz="0 0 1" />
        <parent link="part_1_3" />
        <child link="foot" />
    </joint>
    <joint name="fastened_8" type="fixed">
        <origin xyz="-0.017 0.076775 -0.017856" rpy="0 -1.5708 1.5708" />
        <axis xyz="0 0 1" />
        <parent link="part_1_1" />
        <child link="foot_3" />
    </joint>
    <joint name="fastened_9" type="fixed">
        <origin xyz="4.05808e-18 -6.59589e-18 1.73472e-18" rpy="0 -0 0" />
        <axis xyz="0 0 1" />
        <parent link="top_case" />
        <child link="bottom_case" />
    </joint>
    <joint name="fixed_node_to_root_joint" type="fixed">
        <origin xyz="-3.46945e-18 1.38778e-17 -0.005" rpy="0 -0 0" />
        <axis xyz="0 0 1" />
        <parent link="root" />
        <child link="top_case" />
    </joint>
    <joint name="revolute_1" type="continuous">
        <origin xyz="-0.048 -0.034 -6.93889e-18" rpy="2.90163e-14 2.92384e-14 -1.5708" />
        <axis xyz="-1 0 0" />
        <parent link="leg_middle_part_3" />
        <child link="part_1_3" />
    </joint>
    <joint name="revolute_10" type="continuous">
        <origin xyz="0.0465 -0.0385 -0.0182" rpy="1.5708 -2.46519e-32 -2.22045e-16" />
        <axis xyz="0 -1 0" />
        <parent link="bottom_case" />
        <child link="part_1_2" />
    </joint>
    <joint name="revolute_11" type="continuous">
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

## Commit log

2026-08-20 CubeBot: simulation model, real CAD, and the analysis behind it
    A 12-DOF sprawled quadruped, simulated in MuJoCo and validated against the
    servos it will actually be built with.
    sim/ cubebot.xml (MuJoCo, primitives only, no mesh dependencies) and a
    matching cubebot.urdf generated from it with real masses and inertias
    cad/ the real STLs, plus the URDF collision proxies clearly marked as the
    stand-ins they are
    docs/ the leg statics derivation, fastener census, and handoff
    tools/ the sim, the joint-control panel, gait generator, mass model and audits
    data/ recorded takes and poses
    media/ gait and climb renders
    Servos are SG90 on yaw and SG92R on pitch and knee, rat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
    [3ozjznhu8j9f-Bottom_Cover.stl, 42zlmowk6v3y-Body_Frame.stl, Bottom_case.stl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]
2026-08-20 Rewrite the README as a repo landing page
    Leads with what the robot is and a render of it walking, then the quick start,
    the servo sizing and its validation. Adds the four results that were
    counter-intuitive enough to be worth stating up front, and moves the known
    limitations somewhere a reader will actually see them before trusting the
    numbers.
2026-08-21 Close the mass question with a measurement, and add the build handoff
    Printed parts weighed ~300 g including support. Backing out ~15% support gives
    ~255 g of parts and a ~735 g robot, against the 751.7 g the model runs at — so
    the published loads are correct and mildly conservative.
    The earlier 0.85 effective-fill assumption was wrong; real fill is ~0.55,
    because 15% infill on thin-walled parts is far lighter than assumed. The 873 g
    case that would have put the shoulder servos at their limit does not occur.
    Also adds docs/HANDOFF.md: assembly-day state, the fastener shortfall, the leg
    mount angles and zero-pose convention, and an explicit list of the artifacts in
    this project that are k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
2026-08-21 Soften an overstated claim about gait speed
    "Slower is worse" was firmer than the data supports. RMS shoulder load is
    actually flat between 0.8 and 1.0 Hz (39% vs 38%), and pitch/knee peaks are
    slightly higher at 1.0 Hz, not lower.
    What the measurements do support: slowing down buys no thermal relief, because
    stance torque is the robot's weight on a fixed lever arm and does not scale with
    leg speed, while speed more than halves. Below ~0.5 Hz the load does start
    rising. Both files now say that, and point at stance height as the lever that
    actually reduces load.
2026-08-27 Add the complete STEP assembly
    Full 28-part CubeBot assembly exported from CAD, so the real geometry
    lives alongside the STL exports and the URDF.
2026-08-27 Point the README at the complete STEP assembly
2026-08-28 Name the project RoboSpider in the README title
    File paths under sim/ and cad/ still use the cubebot- prefix and are left
    alone so the links keep resolving.
